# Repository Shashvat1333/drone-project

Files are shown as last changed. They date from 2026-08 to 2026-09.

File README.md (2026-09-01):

# Drone Project

A fully custom quadcopter drone and handheld transmitter, designed from scratch with a self-designed LoRa radio link instead of an off-the-shelf RC system.

Drone Render

> **Project Status:** Mechanical design (CAD) and wiring documentation are complete. Firmware is actively being developed but has not yet been tested. Physical assembly, printing, and flight testing are pending funding approval.

## Table of Contents
- [Overview](#overview)
- [Repository Structure](#repository-structure)
- [CAD Model & Assembly](#cad-model--assembly)
- [Schematic & Wiring](#schematic--wiring)
- [Firmware](#firmware)
- [Getting Started](#getting-started)
- [Bill of Materials (BOM)](#bill-of-materials-bom)
- [License](#license)

## Overview

I am designing a fully custom quadcopter drone and handheld transmitter as a hardware engineering project. The goal is to combine mechanical design, electronics, 3D printing, and embedded systems to create a long-endurance flying platform controlled by a radio system I built myself, rather than an off-the-shelf drone or transmitter.

This project involves selecting and validating components for both the drone and controller, designing custom frames and enclosures in CAD, developing a LoRa-based radio link for control and telemetry, and documenting the full electrical wiring in preparation for manufacturing and assembly.

### Project Goals

- Build a quadcopter capable of 30+ minutes of flight time, prioritizing endurance over racing performance.
- Design and manufacture a custom 3D-printed frame and handheld controller enclosure.
- Build a fully custom transmitter/receiver system using LoRa instead of a commercial radio.
- Implement GPS-based Return-to-Home functionality.
- Learn about flight control systems, RF communication, power systems, and mechanical design under real-world constraints (weight, cost, vibration, torque).
- Create a documented engineering process from initial planning through final assembly.

### Key Technologies

**Mechanical Design**
- CAD modeling (frame, arms, landing legs, controller enclosure)
- 3D printing — planned in PETG filament (Bambu A1 Mini)

**Electronics**
- SpeedyBee F405 V4 flight controller / 4-in-1 ESC stack
- iFlight XING-E Pro 2207 1800KV motors
- BN-880 GPS/compass module
- DIYmalls ESP32 LoRa V3 (SX1262) — drone-side radio
- Heltec WiFi LoRa 32 (SX1262) — controller-side radio/microcontroller
- 6S1P Li-ion battery pack (Flywoo Explorer Molicel P30B 18650)

**Programming / Firmware**
- Embedded C++ (Arduino framework, ESP32/LoRa) — in development
- Flight controller firmware configuration (iNav-compatible) — planned

---

## Repository Structure
```
drone-project/
├── CAD/ # .step files for drone frame, arms, controller enclosure
├── Wiring Diagrams.md # Full wiring reference (drone + controller)
├── Images & Demo/ # Renders, build photos, flight test video
├── BOM.md # Full bill of materials
├── Journal.md # Build log / engineering journal
├── LICENSE.md
└── README.md
```

---

## CAD Model & Assembly

The drone frame, arms, landing legs, and handheld controller enclosure have been custom-designed in CAD, with dimensions driven by the physical footprint of the SpeedyBee stack, motors, and battery pack. Parts are designed to be printed in PETG for a balance of strength and heat resistance around the motor mounts.

All production-ready parts and full assemblies are stored in the [CAD](https://github.com/Shashvat1333/drone-project/tree/main/CAD) folder as `.step` files, ready for printing once funding is approved.

**CAD walkthrough:**

https://github.com/user-attachments/assets/ad44ab19-e9d0-4f68-9096-000306742742

---

## Schematic & Wiring

The drone side connects the flight controller to the ESC stack, motors, GPS/compass module, and the LoRa telemetry radio. The controller side connects a second LoRa radio to dual joysticks and push buttons for manual flight input.

Full pin-by-pin wiring specifications for both the drone and the handheld controller are documented in [Wiring Diagrams.md](Wiring%20Diagrams.md). These layouts are finalized and ready to be wired once the hardware is on hand.

### Drone Wiring

| Component | Component Wire / Pin | Flight Controller / ESC Pad | Function / Notes |
|---|---|---|---|
| XING-E Pro 2207 Motors (x4) | 3 Motor Power Wires (per motor) | ESC Motor Pads (corners of 4-in-1 ESC) | Solder the three wires from each motor directly to the ESC pads |
| SpeedyBee 4-in-1 ESC | ESC Ribbon Cable | SpeedyBee FC Ribbon Cable Port | Plugs directly into the flight controller to bridge power and data |
| Flywoo Molicell 6S Battery | XT60 Main Power Lead | ESC XT60 Power Pads | Main power supply for the entire stack |
| BN-880 GPS & Compass | TX | RX4 (Flight Controller) | GPS data transmit to FC receive |
| BN-880 GPS & Compass | RX | TX4 (Flight Controller) | GPS data receive to FC transmit |
| BN-880 GPS & Compass | SDA | SDA (Flight Controller) | Compass I2C data line |
| BN-880 GPS & Compass | SCL | SCL (Flight Controller) | Compass I2C clock line |
| BN-880 GPS & Compass | 5V / VCC | 4.5V or 5V (Flight Controller) | Power input for GPS |
| BN-880 GPS & Compass | GND | GND (Flight Controller) | Ground reference |
| DIYmalls LoRa ESP32 Board | TX | RX2 (Flight Controller) | Telemetry data transmit to FC receive |
| DIYmalls LoRa ESP32 Board | RX | TX2 (Flight Controller) | Telemetry data receive to FC transmit |
| DIYmalls LoRa ESP32 Board | 5V (or VIN) | 5V (Flight Controller) | Power input |
| DIYmalls LoRa ESP32 Board | GND | GND (Flight Controller) | Ground reference |

### Controller Wiring

| Component | Component Pin / Wire | LoRa Board Pin / Header | Function / Notes |
|---|---|---|---|
| LiPo Battery (3.7V) | Red (+) Wire | JST 1.25mm Connector (Bottom) | Main power supply via onboard connector |
| LiPo Battery (3.7V) | Black (–) Wire | JST 1.25mm Connector (Bottom) | Ground reference via onboard connector |
| Left Joystick (KY-023) | +5V / VCC | 3V3 (Shared power rail/splice) | Shared power input |
| Left Joystick (KY-023) | GND | GND Port (Shared splice) | Shared ground reference |
| Left Joystick (KY-023) | VRX (X-axis) | GPIO 3 (Top Row) | Analog X-axis signal |
| Left Joystick (KY-023) | VRY (Y-axis) | GPIO 4 (Top Row) | Analog Y-axis signal |
| Left Joystick (KY-023) | SW (Switch) | GPIO 5 (Top Row) | Joystick click button input |
| Right Joystick (KY-023) | +5V / VCC | 3V3 (Shared power rail/splice) | Shared power input |
| Right Joystick (KY-023) | GND | GND Port (Shared splice) | Shared ground reference |
| Right Joystick (KY-023) | VRX (X-axis) | GPIO 6 (Top Row) | Analog X-axis signal |
| Right Joystick (KY-023) | VRY (Y-axis) | GPIO 7 (Top Row) | Analog Y-axis signal |
| Right Joystick (KY-023) | SW (Switch) | GPIO 1 (Top Row) | Joystick click button input |
| Left Push Button | Pin 1 | GPIO 2 (Top Row) | Digital input for custom action button |
| Left Push Button | Pin 2 | GND (Shared ground splice) | Pulls pin LOW when pressed |
| Right Push Button | Pin 1 | GPIO 38 (Top Row) | Digital input for custom action button |
| Right Push Button | Pin 2 | GND (Shared ground splice) | Pulls pin LOW when pressed |

---

## Firmware

**Status: In development — not yet written or tested.**

The flight controller will run iNav-compatible firmware, configured (not custom-coded) for stabilization, GPS Return-to-Home, and ESC/motor output.

The LoRa radio link between the drone and the handheld controller requires fully custom firmware, to be written in embedded C++ using the Arduino framework. It will read joystick and button input on the controller side, transmit it over LoRa, and the drone-side ESP32 will relay it into the flight controller as RC/telemetry data.

Firmware development is on hold pending funding for the physical hardware — untested code isn't being published as if it's verified against real boards.

- **Boards to be used:** DIYmalls ESP32 LoRa V3 (SX1262) — drone side; Heltec WiFi LoRa 32 (SX1262) — controller side
- **Flight controller:** SpeedyBee F405 V4, to be configured via iNav

---

## Getting Started

Planned build process once hardware is available:

1. **Print the parts** — *(Pending)* Slice the `.step` files from the [CAD](https://github.com/Shashvat1333/drone-project/tree/main/CAD) folder. Designed for PETG.
2. **Assemble the frame** — *(Pending)* Mount the motors, ESC stack, flight controller, GPS module, and battery according to the CAD model.
3. **Wire the electronics** — *(Pending)* Follow [Wiring Diagrams.md](Wiring%20Diagrams.md) for both the drone and controller wiring.
4. **Flash the firmware** — *(Pending)* Custom LoRa transmitter/receiver firmware is still in development. Once written, it will be uploaded to both the drone-side and controller-side ESP32 boards via the Arduino IDE.
5. **Configure the flight controller** — *(Pending)* Load iNav-compatible firmware onto the SpeedyBee F405 V4 and configure PID tuning, GPS, and Return-to-Home settings.
6. **Test and fly** — *(Pending)* Confirm the LoRa link is transmitting and test flight in a safe, open area.

---

## Bill of Materials (BOM)

Full itemized parts list and pricing available in [BOM.md](https://github.com/Shashvat1333/drone-project/blob/main/BOM.md).

---

## License

This project is licensed under the terms specified in [LICENSE.md](https://github.com/Shashvat1333/drone-project/blob/main/LICENSE.md).

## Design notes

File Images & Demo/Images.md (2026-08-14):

Drone Project IMAGEs
-------------------------------------------------------------------------------------------------------------------------------------------------------------------



-------------------------------------------------------------------------------------------------------------------------------------------------------------------



-------------------------------------------------------------------------------------------------------------------------------------------------------------------



-------------------------------------------------------------------------------------------------------------------------------------------------------------------



-------------------------------------------------------------------------------------------------------------------------------------------------------------------



-------------------------------------------------------------------------------------------------------------------------------------------------------------------



-------------------------------------------------------------------------------------------------------------------------------------------------------------------



-------------------------------------------------------------------------------------------------------------------------------------------------------------------



-------------------------------------------------------------------------------------------------------------------------------------------------------------------



-------------------------------------------------------------------------------------------------------------------------------------------------------------------

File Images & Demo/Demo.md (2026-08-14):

Drone Project DEMOs
-------------------------------------------------------------------------------------------------------------------------------------------------------------------

https://github.com/user-attachments/assets/ad44ab19-e9d0-4f68-9096-000306742742

-------------------------------------------------------------------------------------------------------------------------------------------------------------------

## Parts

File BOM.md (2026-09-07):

Drone Build - Parts List

| # | Part | Price (w/ tax) | Link |
|---|---|---|---|
| 1 | XING-E Pro 2207 1800KV Brushless Motor (4-Pack) | $92.65 | [Amazon](https://www.amazon.ca/1800KV-Brushless-5-6inch-Propeller-Freestyle/dp/B0D791YFCC) |
| 2 | SpeedyBee F405 V4 FC & 55A 4-in-1 ESC Stack | $115.6 | [AliExpress](https://www.aliexpress.com/item/1005012137897324.html) |
| 3 | 4pair IFlight Nazgul F5 5.1x3.5x3 | $10.1 | [AliExpress](https://www.aliexpress.com/item/1005004330581935.html) |
| 4 | Flywoo Explorer Molicell P30B 6S1P 3000mAh Battery | $86 | [EpicFPV](https://epicfpv.ca/products/flywoo-explorer-molicell-p30b-18650-6s1p-3000mah-lionpack-battery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) |
| 5 | BN-880 GNSS Dual GPS Module with QMC5883L Compass | $35.5 | [AliExpress](https://www.aliexpress.com/item/1005009797132645.html) |
| 6 | KY-023 Dual-Axis Joystick Module (x2) | $5.3 | [AliExpress](https://www.aliexpress.com/item/1005012510260347.html) |
| 7 | EEMB 3.7V LiPo Battery 320mAh (JST 1.25mm) | $16.94 | [Amazon](https://www.amazon.ca/EEMB-402535-Rechargeable-Connector-Certified/dp/B08215N9R8) |
| 8 | DIYmalls 915MHz LoRa ESP32 OLED Board V3 (2-Pack) | $66.53 | [Amazon](https://www.amazon.ca/DIYmalls-Antenna-Arduino-LoRawan-Compatible/dp/B09VDJJTDB) |
| 9 | uxcell Mini Tactile Push Button Switch (6-Pack) | $7.67 | [Amazon](https://www.amazon.ca/uxcell%C2%AE-4-5x4-5x3-8mm-Momentary-Tactile-Button/dp/B07HCFVHXM) |
| 10 | Nano Double Sided Adhesive Tape | $8.1 | [AliExpress](https://www.aliexpress.com/item/1005010585928501.html) |
| 11 | KADRICK 420PCS M3 Heat Set Inserts Kit | $25.48 | [Amazon](https://www.amazon.com/Threaded-Assortment-M3x6-30mm-Installation-Printing/dp/B0GYRQG7F2) |
| 12 | LiPo Charger 80W 6A RC Fast Balance Battery Chargers Discharger | $49.72| [Amazon](https://www.amazon.ca/dp/B0G9MDKCW3/ref=sspa_dk_detail_0) |
| 13 | ELEGOO PETG Filament 1.75mm Black 1KG ~ 178.77g Used | $23.72 | [Amazon](https://www.amazon.ca/ELEGOO-Filament-Dimensional-Accuracy-Printers/dp/B0D41Y3WWZ) |
| 14 | GEPRC Battery Strap Good Wear Resistance High Tensile Strength | $15.6 | [AliExpress](https://www.aliexpress.com/item/1005008139076466.html) |
| 15 | TOWOT 63/37 Rosin Core Solder Wire 1.0mm 50g | $14.69 | [Amazon](https://www.amazon.ca/TOWOT-Purity-Electrical-Soldering-Content/dp/B09KM2LW4G) |
| 16 | Eujgoov Smoke Stopper Fuse | $14.1 | [Amazon](https://www.amazon.ca/dp/B0C8TYSR72/ref=sspa_dk_detail_0?) |
| 17 | Soft Silicone Cable Red Black Car Battery Automotive Wiring 22AWG-26AWG | $6.98 | [AliExpress](https://www.aliexpress.com/item/1005008409314314.html?) |

**Import Fees: ~$20**

**Total: $614.68**

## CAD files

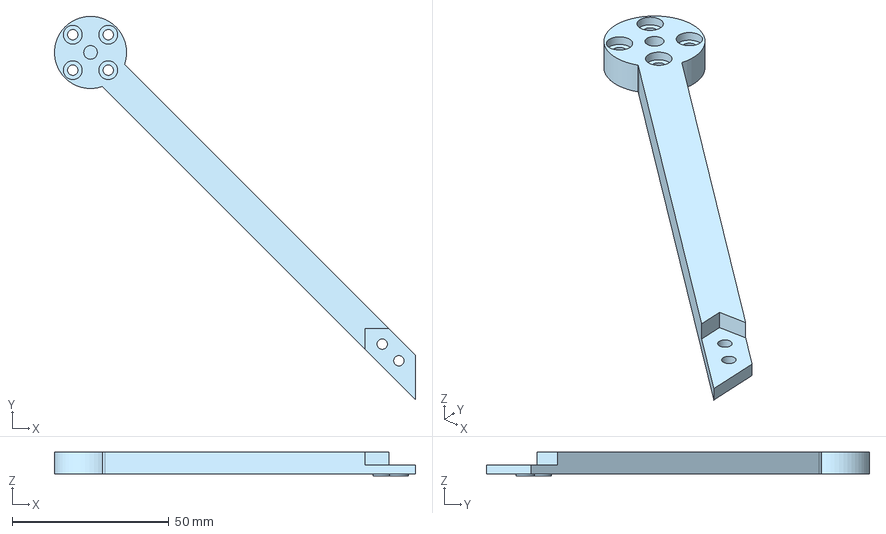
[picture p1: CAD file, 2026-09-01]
CAD/Arm V2 x2.step
115.1 x 122.1 x 7.50 mm

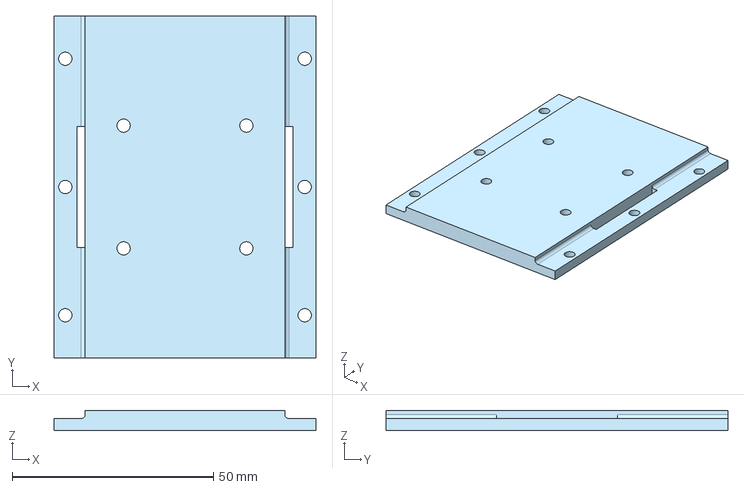
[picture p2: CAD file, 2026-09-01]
CAD/Top.step
65.0 x 85.0 x 5.00 mm

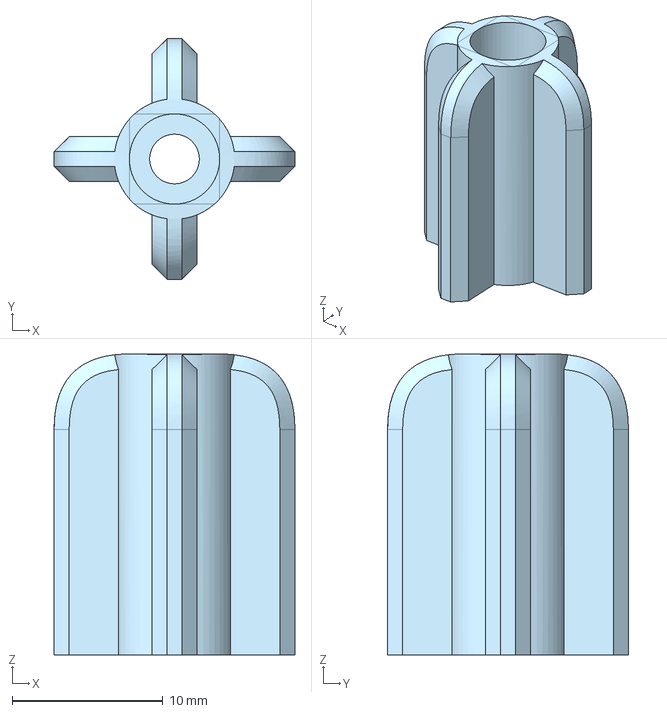
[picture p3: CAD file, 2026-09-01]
CAD/Legs x4.step
16.0 x 16.0 x 20.0 mm

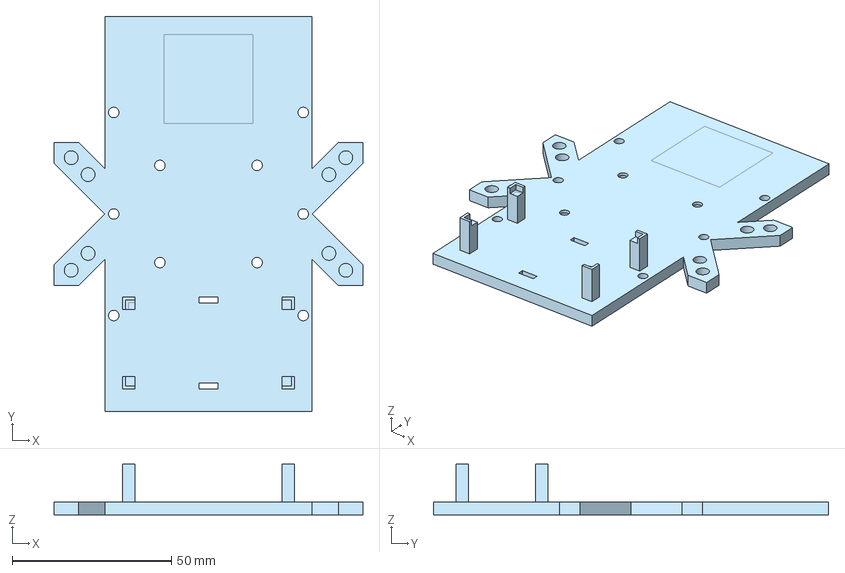
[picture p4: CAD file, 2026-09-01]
CAD/Base.step
97.0 x 124.0 x 16.0 mm

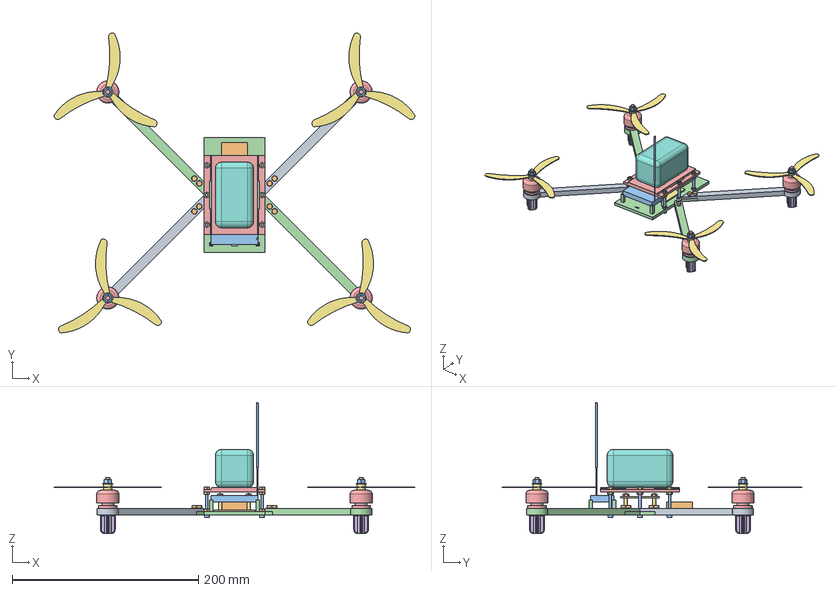
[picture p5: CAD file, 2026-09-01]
CAD/Drone Frame.step
387.8 x 322.0 x 141.0 mm

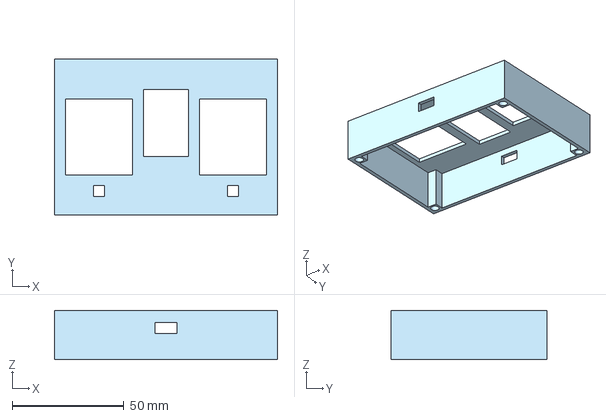
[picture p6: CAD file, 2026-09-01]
CAD/Controller Body.step
100.0 x 70.0 x 22.0 mm

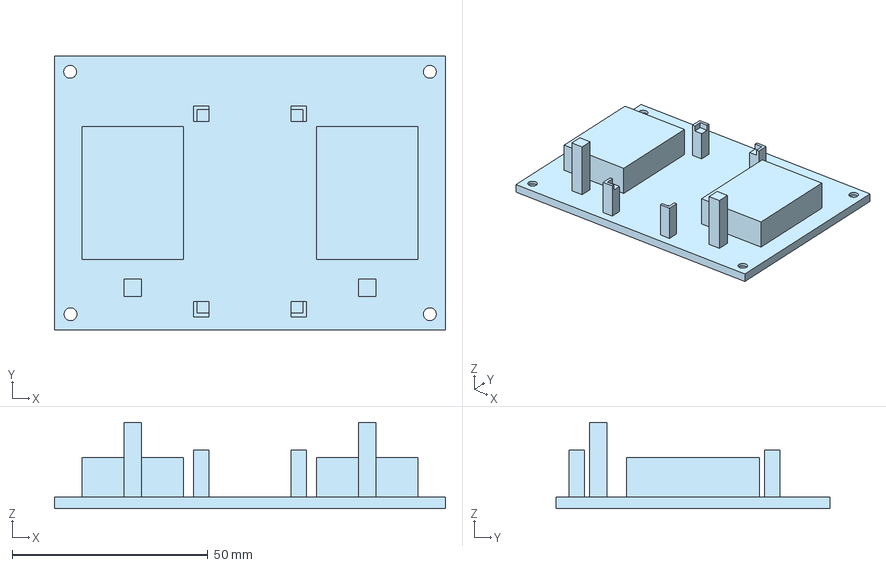
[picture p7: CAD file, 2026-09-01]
CAD/Controller Base.step
100.0 x 70.0 x 22.0 mm

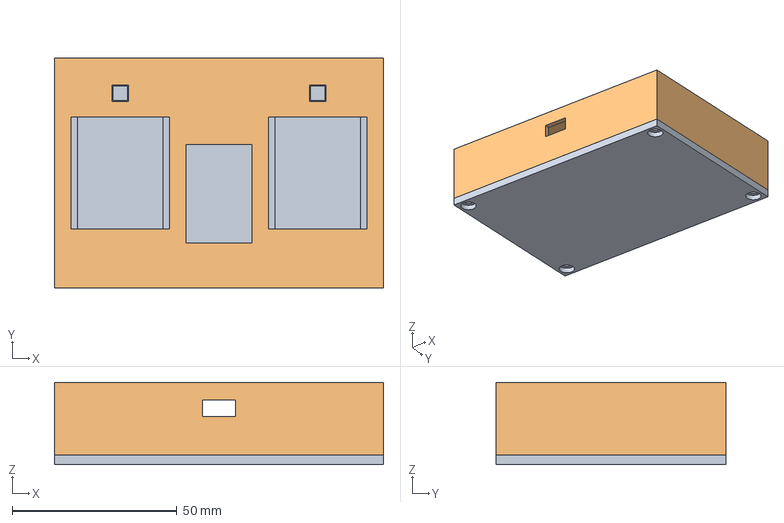
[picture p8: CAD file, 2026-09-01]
CAD/Controller.step
100.0 x 70.0 x 25.0 mm

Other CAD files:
CAD/Arm V1 x2.step

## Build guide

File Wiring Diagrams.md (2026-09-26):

DRONE WRINING DIAGRAMS
-------------------------------------------------------------------------------------------------------------------------------------------------------------------
DRONE
-------------------------------------------------------------------------------------------------------------------------------------------------------------------



-------------------------------------------------------------------------------------------------------------------------------------------------------------------

# Drone-Side Wiring Chart (Final)

| Component | Component Wire / Pin | Flight Controller / ESC Pad | Function / Notes |
|---|---|---|---|
| XING-E Pro 2207 Motors (x4) | 3 Motor Power Wires (per motor) | ESC Motor Pads (corners of 4-in-1 ESC) | Solder any order — wire order doesn't matter, fix spin direction in INAV Motors tab if needed |
| SpeedyBee 4-in-1 ESC | ESC Ribbon Cable | SpeedyBee FC Ribbon Cable Port | Plugs directly into the flight controller to bridge power and data |
| Flywoo Molicell 6S Battery | XT60 Main Power Lead | ESC XT60 Power Pads | Main power supply for the entire stack |
| BN-880 GPS & Compass | **T** (TX) | **R3** (Flight Controller) | GPS data transmit to FC receive — UART3 |
| BN-880 GPS & Compass | **R** (RX) | **T3** (Flight Controller) | GPS data receive to FC transmit |
| BN-880 GPS & Compass | **D** (SDA) | SDA (Flight Controller) | Compass I2C data line |
| BN-880 GPS & Compass | **C** (SCL) | SCL (Flight Controller) | Compass I2C clock line |
| BN-880 GPS & Compass | **V** (VCC) | 4.5V or 5V (Flight Controller) | Power input for GPS |
| BN-880 GPS & Compass | **G** (GND) | GND (Flight Controller) | Ground reference |
| DIYmalls LoRa ESP32 Board | TX | **R2** (Flight Controller) | MSP data transmit to FC receive |
| DIYmalls LoRa ESP32 Board | RX | **T2** (Flight Controller) | Optional — telemetry back from FC (not required for MSP_SET_RAW_RC) |
| DIYmalls LoRa ESP32 Board | 5V (or VIN) | 5V (Flight Controller) | Power input — confirmed via multimeter, 3.3V rail reads correctly |
| DIYmalls LoRa ESP32 Board | GND | GND (Flight Controller) | Ground reference — must be common with FC |
| NRF24L01+PA+LNA | VCC | 3V3 (DIYmalls ESP32 board) | See capacitor note below |
| NRF24L01+PA+LNA | GND | GND (DIYmalls ESP32 board, shared) | |
| NRF24L01+PA+LNA | CE | GPIO 47 (DIYmalls ESP32 board) | |
| NRF24L01+PA+LNA | CSN | GPIO 48 (DIYmalls ESP32 board) | SPI chip select |
| NRF24L01+PA+LNA | SCK | GPIO 33 (DIYmalls ESP32 board) | SPI clock |
| NRF24L01+PA+LNA | MOSI | GPIO 35 (DIYmalls ESP32 board) | SPI data in |
| NRF24L01+PA+LNA | MISO | GPIO 34 (DIYmalls ESP32 board) | SPI data out |
| NRF24L01+PA+LNA | IRQ | Not connected | Unused, code polls instead |
| Decoupling Capacitor (10µF) | + | NRF24 VCC pin | Solder directly at the NRF24 module, as close as possible |
| Decoupling Capacitor (10µF) | − | NRF24 GND pin | Solder directly at the NRF24 module, as close as possible |

------------------------------------------------------------------------------------------------------------------------------------------------------------------
CONTROLLER
-------------------------------------------------------------------------------------------------------------------------------------------------------------------



-------------------------------------------------------------------------------------------------------------------------------------------------------------------

Here is the updated controller wiring chart with both KY-023 joysticks powered by the 5V pin and the NRF24L01 module powered by the 3.3V pin:

# Heltec ESP32 LoRa V3 Remote Controller Wiring Reference

# Remote Controller — Final Wiring Chart

| Component | Component Pin | Board Pin / GPIO | Notes |
|---|---|---|---|
| USB Type-C | — | Type-C port | Power source |
| Left Joystick (KY-023) | VCC | 5V (Bottom Row) | USB-powered only |
| Left Joystick (KY-023) | GND | GND (shared) | |
| Left Joystick (KY-023) | VRX | GPIO 3 | Analog X |
| Left Joystick (KY-023) | VRY | GPIO 4 | Analog Y |
| Left Joystick (KY-023) | SW | GPIO 5 | Click button |
| Right Joystick (KY-023) | VCC | 5V (Bottom Row, shared) | USB-powered only |
| Right Joystick (KY-023) | GND | GND (shared) | |
| Right Joystick (KY-023) | VRX | GPIO 6 | Analog X |
| Right Joystick (KY-023) | VRY | GPIO 7 | Analog Y |
| Right Joystick (KY-023) | SW | GPIO 1 | Click button |
| Left Push Button | Pin 1 | GPIO 2 | Arm/disarm |
| Left Push Button | Pin 2 | GND (shared) | |
| Right Push Button | Pin 1 | GPIO 38 | RTH trigger |
| Right Push Button | Pin 2 | GND (shared) | |
| NRF24L01+PA+LNA | VCC | 3V3 | See capacitor note below |
| NRF24L01+PA+LNA | GND | GND (shared) | |
| NRF24L01+PA+LNA | CE | GPIO 47 | |
| NRF24L01+PA+LNA | CSN | GPIO 48 | SPI chip select |
| NRF24L01+PA+LNA | SCK | GPIO 33 | SPI clock |
| NRF24L01+PA+LNA | MOSI | GPIO 35 | SPI data in |
| NRF24L01+PA+LNA | MISO | GPIO 34 | SPI data out |
| NRF24L01+PA+LNA | IRQ | Not connected | Unused, code polls instead |
| Decoupling Capacitor (10µF electrolytic) | + (long leg) | NRF24 VCC pin | Solder as close to NRF24 module as possible |
| Decoupling Capacitor (10µF electrolytic) | − (short leg / stripe side) | NRF24 GND pin | Solder as close to NRF24 module as possible |

**Capacitor note**: solder it directly across the NRF24's own VCC/GND pins, right at the module — not back near the ESP32. If electrolytic, long leg/unmarked side = +VCC, striped side = −GND.

-------------------------------------------------------------------------------------------------------------------------------------------------------------------

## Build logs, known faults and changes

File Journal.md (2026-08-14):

Drone Project Journal
-------------------------------------------------------------------------------------------------------------------------------------------------------------------

**Day 1**: July 27, 2026

Time spent: **4 hours**

Started planning my custom quadcopter today, both the drone itself and a custom transmitter to go with it. Read through a beginner drone guide to understand the main components like the frame, motors, ESCs, flight controller, GPS, and PDB, then used it as a reference rather than following it exactly. Set my main goals as a carbon fiber frame under 650g, no onboard camera, GPS based Return to Home, and a fully custom handheld transmitter instead of buying one. Learned GPS modules usually come with a built in compass for heading, and that a PDB with a built in 5V regulator simplifies the whole electrical system. Also learned drones typically skip traditional fuses since motor current changes too fast, using a smoke stopper instead during first power on. Looked at ESP32 with ESP-NOW or WiFi for the transmitter but the range and failsafe reliability weren't good enough, so decided on EdgeTX firmware with an ExpressLRS radio module instead.
Next: research and select the frame, motors, ESCs, flight controller, receiver, GPS, battery, and PDB, then start the bill of materials.



-------------------------------------------------------------------------------------------------------------------------------------------------------------------

**Day 2**: July 28, 2026

Time spent: **4 hours**

Finalized the main hardware for both the drone and the custom controller. Picked the SpeedyBee F405 V4 flight stack, iFlight XING-E Pro 2207 1800KV motors, Gemfan Hurricane 51433 props, a Tattu R-Line 6S battery, and the BN-880 GPS with built in compass, no FPV camera to keep weight down. For the controller, went with an ESP32-C3 Super Mini, HC-12 wireless module, KY-023 joysticks, a rechargeable LiPo, and a TP4056 USB-C charging module. Learned how the TP4056 charging circuit should be wired, with the battery going into the module and the module powering the ESP32. Also learned adding electrolytic capacitors helps cut down voltage spikes and noise. Estimated total project cost around $400 to 500 CAD.
Next: start designing the carbon fiber frame in CAD, design the controller enclosure, build out the wiring diagrams.



-------------------------------------------------------------------------------------------------------------------------------------------------------------------

**Day 3**: July 29, 2026

Time spent: **3 hours**

Switched the controller design from a separate ESP32 and radio module to the Heltec WiFi LoRa 32 (SX1262) board, which combines both into one and cuts down on wiring. Picked a 3.7V 320mAh LiPo with a 1.25mm JST connector that plugs right into the Heltec board and charges through its built in USB-C. Started on the drone frame and considered switching from carbon fiber to PLA+ since it's cheaper and faster to make while still meeting the weight target. Confirmed the iFlight XING2 motors use M3 screws and worked out that 8mm M3 screws with 3.2mm holes fit a 4mm thick arm properly. Planned arm width at 10 to 15mm for strength without adding much weight, and picked M3 nylon standoffs to isolate the flight controller from the frame.
Next: keep designing the frame, decide between carbon fiber and PLA+, design the controller enclosure around the Heltec board.



-------------------------------------------------------------------------------------------------------------------------------------------------------------------

**Day 4**: July 30, 2026

Time spent: **4 hours**

Compared PLA+, carbon fiber, and PETG for the frame and landed on PETG after weighing flex, crash durability, and cost. Worked through arm and base plate dimensions in CAD to handle 6S motor torque without too much flex. Learned 3D printed frames flex more than CNC cut carbon fiber under high torque, which can cause gyro vibration issues, but decided the cost of CNC cutting wasn't worth it over a properly reinforced PETG frame. Mapped out how the DIYmalls ESP32 LoRa boards will handle both control commands and telemetry over the same radio link, learned the SX1262 chip is half duplex so one module can do both jobs. Also learned the SpeedyBee stack already has a built in voltage sensor, so I just need to route that over UART to the LoRa board. Decided to use foam tape to mount the GPS and LoRa board since it absorbs vibration well, and picked M3 brass heat set inserts with steel bolts for attaching the modular arms.
Next: finalize the CAD for the modular arms with the insert mounting points built in, design the enclosure with proper wall thickness and vent holes.



-------------------------------------------------------------------------------------------------------------------------------------------------------------------

**Day 5**: July 31, 2026

Time spent: **3 hours**

Stepped back and reviewed the whole build to improve efficiency and flight time without hurting reliability. Realized some of my original parts were picked more for racing than long endurance flight. Switched to the iFlight XING-E Pro 2207 1800KV motors for better efficiency and kept the SpeedyBee F405 V4 stack since it already covers what I need. Biggest change was the battery, my original Tattu R-Line 1550mAh 4S LiPo would've only given 4 to 6 minutes of flight time, so I switched to the Flywoo Explorer Lionpack BAK P45D 21700 4S1P 4500mAh Li-ion battery, which runs at the same voltage and uses the same XT60 connector so no wiring changes needed. Picked up a SkyRC B6Neo charger to handle both Li-ion and LiPo safely. Got the frame CAD to about 50% done and settled on 7mm thick, 10mm wide arms with internal infill. Also confirmed my Bambu A1 Mini and Elegoo PETG filament will work fine for printing the frame without any upgrades needed.
Next: keep working through the rest of the frame CAD, refine based on the prototype before final assembly.



-------------------------------------------------------------------------------------------------------------------------------------------------------------------

**Day 6**: August 1, 2026

Time spent: **2 hours 46 minutes**

Finished the drone frame CAD and got the controller design close to done. Built a full CAD assembly of the frame with proxy M3 screws to see how everything fits together as a whole instead of piece by piece, which made it a lot easier to catch clearance and alignment issues before manufacturing. Also designed the landing legs to give the drone proper ground clearance.
Next: finish the remaining controller CAD, do a final review of the full drone assembly before manufacturing.



-------------------------------------------------------------------------------------------------------------------------------------------------------------------

**Day 7**: August 2, 2026

Time spent: **3 hours**

Finished the CAD for the handheld controller, wrapping up the mechanical design for both the drone and controller. Built a full assembly of the controller and found a few missing parts and small design issues that weren't obvious when working on individual pieces, fixed those before calling it ready for manufacturing. Also started the wiring diagrams in Cirkit Designer and finished the full drone diagram, mapping out the flight controller, 4-in-1 ESC, motors, GPS, LoRa receiver, battery, and everything else.
Next: finish the controller wiring diagram, review the full parts list one more time, apply for funding, then order components once approved.



-------------------------------------------------------------------------------------------------------------------------------------------------------------------

**Day 8**: August 5, 2026

Time spent: **3 hours**

Built out proxy parts for the drone assembly today including the ESC, motors, propellers, and flight controller. Having accurate models instead of placeholder shapes made it a lot easier to see what the final product will actually look like put together. Found several screw hole sizing issues throughout the frame, some too large and some too small for the actual hardware, and went through and fixed each one. Also ran into a specific problem with the FC and ESC stack where the screws I'd planned to use were too big to attach the 4-in-1 ESC and flight controller together properly, so I'm switching to a smaller size from my M3 kit once funding comes through. Made a few structural changes too, adding material in some spots for stability and trimming it elsewhere to save weight.
Next: order the smaller screws once funded, keep refining the frame, move toward finalizing before manufacturing.



-------------------------------------------------------------------------------------------------------------------------------------------------------------------

**Day 9**: August 6, 2026

Time spent: **3 hours**

Made a big change to the battery setup today. Was originally planning to use the Flywoo Explorer Lionpack BAK P45D 4S1P 4500mAh pack, but switched to the Flywoo Explorer Molicel P30B 18650 6S1P 3000mAh instead to get better flight times and efficiency. Going from 4S to 6S bumps up the system voltage, which lets the motors spin more efficiently under load while pulling fewer amps for the same output, so better performance and endurance overall. Finished the full Bill of Materials today too, landing on just over $700 CAD for the complete build. Had to redo my wiring diagram in Cirkit after realizing I never saved the last version, but got through it and finished both the drone and controller diagrams. Also finished the demo video for the drone, spent some extra time making it look realistic by having two propellers spin clockwise and the other two counterclockwise to match how a real quadcopter actually flies. Did a full review of everything so far and didn't find any issues, so the design's in a solid finished state.
Next: apply for funding, then move into printing custom parts and ordering the rest of the components.

https://github.com/user-attachments/assets/ad44ab19-e9d0-4f68-9096-000306742742

-------------------------------------------------------------------------------------------------------------------------------------------------------------------

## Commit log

2026-07-30 Update Journal with Day 4 details
    Documented Day 4 progress on drone project, including material choices, design decisions, and lessons learned.
2026-08-01 Update Journal with Day 6 CAD design details
    Documented Day 6 progress on CAD design for drone project, including frame completion and controller refinement.
2026-08-02 Update Journal with Day 7 progress
    Documented progress on CAD design and wiring diagrams for the custom handheld controller and drone.
2026-08-06 Add entry for Day 17 of drone assembly project
    Documented progress on drone assembly, including issues and next steps.
2026-08-07 Update Journal.md with Day 9 entry
    Documented Day 9 progress on battery setup and project status.
2026-08-09 Correct journal entry dates and update battery details
    Updated the dates for Day 8 and Day 9 entries in the journal to reflect the correct dates. Adjusted details regarding the battery setup and changes made during the drone assembly process.
2026-08-14 Complete CAD design and start wiring diagrams
    Finalized the CAD design for the drone frame and handheld controller, addressing clearance and alignment issues. Began wiring diagrams for the drone's electronics.
2026-08-25 Create Wiring Diagrams.md
2026-08-25 Add wiring diagrams for drone and controller
    Added wiring diagrams for drone and controller with images.
2026-08-25 Update Wiring Diagrams with component details
    Added detailed wiring diagrams for drone components including motors, ESC, battery, GPS, and telemetry board.
2026-08-25 Update formatting in Wiring Diagrams.md
2026-08-25 Update wiring diagram formatting and controller section
2026-08-25 Add wiring diagram for components and connections
2026-08-27 Update price for Flywoo Explorer Battery
    Updated the price of the Flywoo Explorer Molicell P30B 6S1P 3000mAh Battery from $116.66 to $86.
2026-08-27 Modify SpeedyBee ESC price and source link
    Updated the price and link for the SpeedyBee F405 V4 FC & 55A 4-in-1 ESC Stack.
2026-08-27 Update propeller entry in BOM
    Replaced HQProp propellers with IFlight Nazgul propellers in the BOM.
2026-08-27 Modify entry for SKYRC B6Neo Charger in BOM
    Updated the description and price for the SKYRC B6Neo Balance Charger.
2026-08-27 Fix link format for GEPRC Battery Strap
2026-08-27 Update total cost in BOM.md
2026-08-27 Modify ELEGOO PETG Filament entry in BOM
    Updated the entry for ELEGOO PETG Filament to include usage details.
2026-09-01 Refine README2.md for clarity and project status
    Updated wording for clarity and corrected phrasing throughout the README2.md file. Added notes about pending hardware and funding for various project stages.
2026-09-07 Update BOM with new item and total cost
    Updated total cost and added a new item to the BOM.
2026-09-07 Add new item and update total in BOM.md
    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
2026-09-23 Revise controller wiring chart with power specifications
    Updated wiring diagram to include power details for joysticks and NRF24L01 module.
2026-09-23 Revise wiring diagram for controller components
    Updated the wiring diagram for the controller to include detailed connections for both KY-023 joysticks and the NRF24L01 module.
2026-09-23 Revise wiring diagram with USB power and new components
    Updated wiring chart for the Heltec ESP32 LoRa V3 Remote Controller to include USB power source and additional components.
2026-09-26 Revise Drone-Side Wiring Chart with detailed connections
    Updated wiring chart for BN-880 GPS, DIYmalls LoRa ESP32 Board, and NRF24L01 module with detailed pin connections and notes.
